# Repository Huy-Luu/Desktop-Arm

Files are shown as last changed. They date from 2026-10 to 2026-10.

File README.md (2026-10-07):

# 🦾 Desktop AI Robot Arm

An educational, 6-DOF (Degree of Freedom) desktop robotic manipulator integrated with the **Desktop Assistant** companion robot, serving as a hands-on learning laboratory for mastering **Robotic AI, Google MuJoCo Simulation, Reinforcement Learning, Embedded Firmware, KiCad PCB, and FreeCAD CAD**.

---

## 📌 Start Here

If you are returning to this project or starting a new session, open the dedicated beginner guide:
👉 **[📖 Beginner Guide & Master Roadmap](docs/BEGINNER_GUIDE_AND_ROADMAP.md)**

This guide explains:
1. **Why we train in simulation first** (Safety, Speed, and Instant Iteration).
2. **Key concepts demystified** (*Homography, Synthetic Test Harness, Domain Randomization, ONNX*).
3. **The 4-Phase Master Roadmap** from virtual simulation to physical desk manipulation.
4. **Current ticket status & next steps**.

---

## 🏛️ Project Directory Structure

```text
deskto-AI-arm/
├── README.md                      # Project root overview (this file)
├── MISSION.md                     # Why this project exists & definition of success
├── GLOSSARY.md                    # Ubiquitous robotics & AI domain dictionary
├── NOTES.md                       # Architectural decisions & hardware preferences
├── RESOURCES.md                   # High-trust documentation and community links
│
├── docs/
│   ├── BEGINNER_GUIDE_AND_ROADMAP.md # Comprehensive guide and master roadmap
│   ├── SYSTEM_DESIGN_DOCUMENT.md     # Authoritative Master System Design Document
│   ├── SPEC-0001-desktop-ai-arm.md   # Complete system architecture specification
│   ├── adr/                          # Architectural Decision Records (ADRs 0001–0005)
│   └── tickets/                      # Tracer-bullet tickets (TICKET-01 to TICKET-12)
│
├── software/
│   ├── models/
│   │   └── desktop_arm_6dof.xml      # Google DeepMind MuJoCo 6-DOF arm physics model
│   ├── arm_env_3d.py                 # Gymnasium continuous-control environment
│   ├── test_sim.py                   # Sanity test verifying 6-DOF physics simulation
│   ├── train_arm_3d_6dof.ipynb       # Google Colab GPU training notebook (PPO)
│   └── gemini_vision_planner.py      # Google Gemini 2.0 Flash spatial perception
│
├── hardware/                         # FreeCAD 3D models & KiCad base controller schematics
├── firmware/                         # ESP32-S3 FreeRTOS motor control & StallGuard4 homing
└── reference/                        # Quick-reference cheatsheets & fundamentals
```

---

## 🚦 Current Status & Next Step

- **TICKET-01 (Simulation Verification)**: ✅ **COMPLETED**. MuJoCo 6-DOF environment verified with [test_sim.py](file:///mnt/g/projects/deskto-AI-arm/software/test_sim.py).
- **TICKET-02 (Colab PPO Training & ONNX Export)**: ✅ **COMPLETED**. Vectorized notebook with Domain Randomization and ONNX actor export ready in [software/train_arm_3d_6dof.ipynb](file:///mnt/g/projects/deskto-AI-arm/software/train_arm_3d_6dof.ipynb). See [Lesson 0001](file:///mnt/g/projects/deskto-AI-arm/lessons/0001-colab-ppo-and-domain-randomization.html) and [test_ticket02.py](file:///mnt/g/projects/deskto-AI-arm/software/test_ticket02.py).
- **TICKET-03 (Local PC ONNX Inference & Workspace Geofence)**: 🎯 **CURRENT NEXT STEP**. Deploy `arm_policy.onnx` locally on CPU with 3D table safety boundaries.

To resume at any time in a new chat, simply tell the assistant:
> *"I'm ready to continue. Let's work on TICKET-03 (Local PC ONNX Inference and Workspace Geofencing)."*

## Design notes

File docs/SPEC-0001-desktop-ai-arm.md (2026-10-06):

# SPEC-0001: Desktop AI Robot Arm & Desktop Assistant Integration

- **Status**: Ready for Implementation (`ready-for-agent`)
- **Date**: 2026-10-04
- **Related ADRs**:
  - [ADR 0001: Hybrid Stepper-Servo Actuation & Wireless Docking](file:///mnt/g/projects/deskto-AI-arm/docs/adr/0001-hybrid-stepper-servo-and-wireless-docking.md)
  - [ADR 0002: Sensorless Homing, Base-Mounted Belt Drive, and WebSocket Architecture](file:///mnt/g/projects/deskto-AI-arm/docs/adr/0002-sensorless-homing-base-steppers-and-websockets.md)
  - [ADR 0003: 24V Bus, PLA Thermal Mitigation, and Rack-and-Pinion Gripper](file:///mnt/g/projects/deskto-AI-arm/docs/adr/0003-power-delivery-thermal-pla-and-rack-pinion-gripper.md)
  - [ADR 0004: Conversational Disambiguation, ONNX Runtime Inference, and Domain Randomization](file:///mnt/g/projects/deskto-AI-arm/docs/adr/0004-conversational-ambiguity-onnx-and-domain-randomization.md)
  - [ADR 0005: Hierarchical Grasping, Overhead Homography, and S-Curve Motion Execution](file:///mnt/g/projects/deskto-AI-arm/docs/adr/0005-hierarchical-grasping-homography-and-scurve-motion.md)
- **Authoritative Master Design**: [SYSTEM_DESIGN_DOCUMENT.md](file:///mnt/g/projects/deskto-AI-arm/docs/SYSTEM_DESIGN_DOCUMENT.md)

---

## Problem Statement

As a beginner to robotics, AI, and electronics, building a desktop manipulator from scratch is daunting due to the complex convergence of mechanical design, kinematics math, PCB layout, and modern neural network control. Furthermore, desktop robots typically lack emotional personality and intuitive natural language interfaces, while existing hobby arms suffer from servo jitter, gear backlash, loud whining, and dangerous lack of collision detection.

The user needs a modular, quiet, precise desktop 6-DOF robot arm that physically integrates with their sibling **Desktop Assistant** (providing expressive eyes and voice interaction), uses cloud compute (Google Colab / MuJoCo) for accelerated AI training, and executes safe, intelligent object manipulation on a desk.

---

## Solution

A desktop-sized 6-DOF hybrid manipulator featuring:
1. **Physical & Electrical Dock**: An arm base cradle with ENIG gold pads mating with Desktop Assistant's `KZM05P03UFT2-B` pogo pins, delivering 5V 3A charging and automatic dock presence detection.
2. **Hybrid Stepper-Servo Drive**: NEMA 14/17 steppers with Trinamic TMC2209 silent drivers and GT2 belt reduction for the high-torque base and shoulder/elbow joints, combined with lightweight micro-servos for the wrist and rack-and-pinion gripper.
3. **Sensorless Homing & Safety**: StallGuard4 back-EMF detection for wire-free homing and automatic emergency cut-off upon collision, backed by software workspace geofencing.
4. **Cloud-Trained Sim-to-Real Policy**: A continuous-control PPO policy trained with domain randomization in Google DeepMind's MuJoCo physics engine on Google Colab, exported to ONNX for lightweight sub-5ms local PC execution.
5. **Conversational Multi-Modal Intelligence**: Overhead webcam scene parsing via Google Gemini 2.0 Flash with conversational disambiguation streamed through Desktop Assistant's microphone and speaker.

---

## User Stories

1. As a user, I want to dock my Desktop Assistant onto the robot arm's base cradle, so that its battery charges automatically via pogo pins.
2. As a user, I want the arm controller to instantly detect when Desktop Assistant is seated, so that it can trigger a greeting animation and report system readiness.
3. As a user, I want Desktop Assistant to continue working wirelessly on internal battery when unseated, so that I can hold it or place it anywhere on my desk while commanding the arm.
4. As a user, I want to speak natural voice commands (e.g., *"Pick up the marker"*) to Desktop Assistant, so that the robot performs object manipulation without requiring keyboard controls.
5. As a user, I want the robot to ask me for clarification through Desktop Assistant's speaker when multiple similar objects are on the table, so that it never grabs the wrong item by mistake.
6. As a user, I want Desktop Assistant's circular LCD to display expressive facial emotions (focused eyes while tracking, happy face on successful grasp, confused face on obstacle), so that the robotic system feels alive and engaging.
7. As a user, I want the arm's base and shoulder joints to operate silently using TMC2209 StealthChop2, so that the arm does not produce irritating high-pitch servo whine on my desk.
8. As a user, I want the arm to home itself automatically on boot without external limit switch wires, so that the mechanical links remain clean and aesthetically pleasing.
9. As a user, I want the arm to immediately stop and cut motor torque if it accidentally bumps into my hand or a desktop object, so that neither the 3D printed parts nor desk items are damaged.
10. As a user, I want to train the motion policy in Google DeepMind MuJoCo on Google Colab using free cloud GPUs, so that I can train complex neural control policies without requiring an expensive local GPU workstation.
11. As a user, I want the trained AI policy exported as an ONNX model, so that my local PC can run real-time inference with minimal CPU usage and zero PyTorch dependencies.
12. As a user, I want the AI policy trained with domain randomization in simulation, so that it transfers seamlessly to the physical 3D-printed arm despite minor belt compliance and friction differences.
13. As a user, I want the structural links printable in standard PLA with active thermal cooling, so that I can fabricate the arm on any basic 3D printer without warping.
14. As a user, I want a symmetrical parallel-jaw rack-and-pinion gripper, so that small cylindrical and rectangular desk items are grasped securely along the tool centerline.
15. As a developer, I want all messaging between PC, Desktop Assistant, and Arm Base to use structured JSON over WebSockets, so that telemetry and commands can be inspected easily in standard tools.

---

## Implementation Decisions

### 1. Electrical & Power Subsystem (Base Controller PCB)
- **Power Input**: 24V 5A DC barrel jack (2.1x5.5mm) with `SMBJ28A` TVS diode and P-channel MOSFET reverse polarity protection.
- **Buck Converter**: `TPS54302` (handles up to 28V input) generating 5.0V @ 3A for Desktop Assistant charging and servo bus, protected by a 2A PPTC resettable fuse.
- **LDO Regulator**: 3.3V low-dropout regulator for base ESP32-S3 MCU and logic.
- **Stepper Drivers**: 3x TMC2209 silent step/dir drivers configured over single-wire UART for software current control and StallGuard sensitivity tuning.
- **Dock Connector**: 5-pad ENIG gold interface matching Desktop Assistant `KZM05P03UFT2-B` pogo pins (`VBUS_5V`, `UART_TX`, `UART_RX`, `DOCK_DETECT_N`, `GND`).

### 2. Mechanical Subsystem (FreeCAD & PLA Fabrication)
- **Base Enclosure**: Encloses the base controller PCB, 24V input jack, 4010 cooling fan, and houses the Base Yaw NEMA 17 motor.
- **Top Deck**: Features a recessed cradle with dual N52 alignment magnets and gold pogo contact pads to hold Desktop Assistant.
- **Belt Drive**: 2GT synchronous timing belts (6mm width) transferring torque from base-mounted steppers to the shoulder and elbow pivot bearings.
- **End-Effector**: Dual rack-and-pinion parallel gripper driven by a single metal-gear micro-servo (MG90S) with silicone contact pads.

### 3. Firmware Subsystem (ESP32-S3 Arm Controller)
- **Framework**: ESP-IDF with FreeRTOS.
- **Stepper Engine**: Hardware timer generating smooth acceleration S-curves (Jerk-limited motion).
- **Homing State Machine**: Boots $\to$ lowers current to 200mA $\to$ moves towards hard stop $\to$ detects `DIAG` pin trigger $\to$ sets coordinate to zero $\to$ backs off 2mm $\to$ restores run current (600mA).
- **Network Interface**: WebSocket client connecting to PC WebSocket server; binary/JSON packet handler.

### 4. Software & AI Subsystem (Host PC & Google Colab)
- **Simulation**: Headless MuJoCo 3.x environment (`software/arm_env_3d.py`) modeling 6 articulated joints, table plane, and 3D reaching target.
- **Cloud Training**: Google Colab notebook (`software/train_arm_3d_6dof.ipynb`) running Stable-Baselines3 PPO with vectorized parallel environments and domain randomization.
- **Model Deployment**: Policy actor exported to `software/models/arm_policy.onnx`, evaluated locally on PC using `onnxruntime`.
- **Vision Pipeline**: Overhead webcam captures desk frame; Google Gemini 2.0 Flash (`software/gemini_vision_planner.py`) outputs target coordinates $[X, Y, Z]$ and handles conversational disambiguation.

---

## Testing Decisions

### Seams & Boundaries
1. **Simulation Seam (`DesktopArm3DEnv`)**: Verify the MuJoCo simulation environment independently via `software/test_sim.py` (reset, step, reward calculation, observation space bounds).
2. **ONNX Inference Seam**: Unit test verifying `onnxruntime` produces valid joint delta actions matching the PyTorch policy output within a numerical tolerance ($\epsilon < 10^{-4}$).
3. **Kinematics Math Seam**: Forward and Inverse Kinematics unit tests comparing analytical matrix calculations against MuJoCo physics forward kinematics.
4. **WebSocket Protocol Seam**: Mock WebSocket server testing message parsing, dock presence events, and emergency stop trigger responses.
5. **Firmware Motor Seam**: Hardware-in-the-loop test commanding 1,000 microsteps and verifying zero step loss.

---

## Out of Scope

- High-voltage industrial servo drives (48V+).
- Heavy metal CNC milling of arm links (all parts optimized for FDM 3D printing).
- SLAM or mobile navigation (the arm base is a desktop stationary unit).
- Training vision models from scratch (leveraging Google Gemini 2.0 Flash foundation model).

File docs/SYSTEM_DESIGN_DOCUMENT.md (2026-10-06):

# SYSTEM-DESIGN-0001: Desktop AI Robot Arm & Desktop Assistant Ecosystem

- **Document Version**: 1.0.0
- **Status**: Authoritative Master Design Specification (`approved-for-execution`)
- **Date**: 2026-10-06
- **System Deciders**: User & Antigravity Engineering Pair
- **Associated ADRs**:
  - [ADR 0001: Hybrid Stepper-Servo Actuation & Wireless Docking](file:///mnt/g/projects/deskto-AI-arm/docs/adr/0001-hybrid-stepper-servo-and-wireless-docking.md)
  - [ADR 0002: Sensorless Homing, Base-Mounted Belt Drive, and WebSocket Architecture](file:///mnt/g/projects/deskto-AI-arm/docs/adr/0002-sensorless-homing-base-steppers-and-websockets.md)
  - [ADR 0003: 24V Bus, PLA Thermal Mitigation, and Rack-and-Pinion Gripper](file:///mnt/g/projects/deskto-AI-arm/docs/adr/0003-power-delivery-thermal-pla-and-rack-pinion-gripper.md)
  - [ADR 0004: Conversational Disambiguation, ONNX Runtime Inference, and Domain Randomization](file:///mnt/g/projects/deskto-AI-arm/docs/adr/0004-conversational-ambiguity-onnx-and-domain-randomization.md)
  - [ADR 0005: Hierarchical Grasping, Overhead Homography, and S-Curve Motion Execution](file:///mnt/g/projects/deskto-AI-arm/docs/adr/0005-hierarchical-grasping-homography-and-scurve-motion.md)
- **Domain Glossary**: [GLOSSARY.md](file:///mnt/g/projects/deskto-AI-arm/GLOSSARY.md)
- **Project Mission**: [MISSION.md](file:///mnt/g/projects/deskto-AI-arm/MISSION.md)

---

## 1. Executive Summary & System Vision

The **Desktop AI Robot Arm** is a modular, desktop-scale 6-DOF robotic manipulation system integrated with a companion **Desktop Assistant**. It serves as an accessible, high-performance hands-on laboratory for mastering modern robotic artificial intelligence, Google cloud-accelerated reinforcement learning, embedded motion firmware, PCB design, and mechanical engineering.

```
       ┌────────────────────────────────────────────────────────┐
       │             Google Colab Cloud Training                │
       │  - Headless MuJoCo 3.x Physics (16 Parallel Envs)     │
       │  - Stable-Baselines3 PPO with Domain Randomization     │
       │  - Exports: software/models/arm_policy.onnx           │
       └───────────────────────────┬────────────────────────────┘
                                   │ Model Download (.onnx)
                                   ▼
┌───────────────────────────┐             ┌─────────────────────────────┐
│    Overhead Camera Rig    │             │   Desktop Assistant Head    │
│  - Fixed table view       │             │  - Circular LCD face/eyes   │
│  - 4-point ArUco homography│             │  - Voice mic & speaker      │
└─────────────┬─────────────┘             │  - Untethered Wi-Fi battery │
              │ Video Frames              └──────────────┬──────────────┘
              ▼                                          │ Audio / UI Events
┌────────────────────────────────────────────────────────┴──────────────┐
│                    Host PC Orchestration Engine                       │
│  - Perception: Google Gemini 2.0 Flash (Spatial Object Reasoning)     │
│  - Disambiguation: Multi-turn conversational clarification           │
│  - Motion Brain: Local ONNX Runtime (<5ms CPU inference)              │
│  - Safety: 3D Cartesian Workspace Geofence Layer                      │
│  - Communication Broker: Full-Duplex JSON-over-WebSocket Server       │
└──────────────────────────────────┬────────────────────────────────────┘
                                   │ Target Waypoints & Commands (JSON)
                                   ▼
┌───────────────────────────────────────────────────────────────────────┐
│               Arm Base Controller & Physical Robot                    │
│  - MCU: ESP32-S3 (Dual-core 240MHz, FreeRTOS, S-Curve Step Generator) │
│  - Power: 24V 5A DC bus + TPS54302 Buck (5V 3A) + 3.3V LDO            │
│  - Steppers: 3x TMC2209 silent drivers (Base, Shoulder, Elbow)        │
│  - Servos: 3x Metal-gear micro-servos (Forearm, Wrist, Gripper)       │
│  - Dock: 5-pad ENIG gold pogo cradle (5V charging + dock presence)    │
│  - Safety: StallGuard4 sensorless homing + obstacle torque cut-off   │
└───────────────────────────────────────────────────────────────────────┘
```

### Core Design Pillars
1. **Simulation-First Development**: Full physics modeling in Google DeepMind MuJoCo before physical fabrication, guaranteeing zero hardware damage, 20-minute cloud GPU training runs, and rapid kinematic tuning.
2. **Hierarchical Control Pipeline**: Decoupling 3D spatial reaching (learned by cloud PPO) from contact-rich grasping (executed by deterministic descent-pinch-lift motion primitives) to achieve rock-solid physical tabletop reliability.
3. **Silent Desktop Presence**: Combining Trinamic TMC2209 StealthChop2 silent stepper drivers for high-torque base axes with lightweight metal-gear micro-servos for the wrist, eliminating irritating servo buzz and whine.
4. **Seamless Companion Symbiosis**: The Desktop Assistant mechanically and electrically seats into an ENIG gold pogo dock on the arm's base, receiving 5V 3A charging and providing expressive eyes, speech, and conversational disambiguation.

---

## 2. End-to-End System Architecture & Data Flow

```mermaid
sequenceDiagram
    autonumber
    actor User as User
    participant Head as Desktop Assistant (Head)
    participant PC as Host PC Orchestrator
    participant Cloud as Gemini 2.0 Flash API
    participant ONNX as ONNX Inference Engine
    participant Arm as ESP32-S3 Base Controller
    participant Cam as Overhead Camera

    Note over Arm,Head: System Boot & Calibration
    Arm->>Arm: Execute StallGuard4 Sensorless Homing (200mA)
    Arm-->>PC: WebSocket: ARM_STATUS (homed=true, docked=true)
    Head-->>PC: WebSocket: ASSISTANT_STATUS (battery=100%, state=idle)

    Note over User,Arm: Task Execution Flow
    User->>Head: "Pick up the blue marker"
    Head->>PC: Stream user audio transcript
    PC->>Cam: Capture desk frame (1920x1080)
    PC->>Cloud: Send image + instruction prompt
    
    alt Ambiguity Detected (Multiple Blue Objects)
        Cloud-->>PC: JSON {action: "disambiguate", prompt: "Which blue marker?"}
        PC->>Head: Play voice prompt & display questioning eyes
        User->>Head: "The one near the notebook"
        Head->>PC: Forward clarification
        PC->>Cloud: Re-prompt with context
    end

    Cloud-->>PC: JSON {target_detected: true, u_norm: 0.52, v_norm: 0.64, grasp_yaw: 0.0}
    PC->>PC: Homography Transform: (u, v) -> Table (X, Y) in meters
    PC->>PC: Formulate Pre-Grasp Waypoint: P_pre = (X, Y, Z_table + 0.05m)
    
    loop 40Hz Policy Rollout (or Direct IK Waypoint)
        PC->>ONNX: Evaluate policy(obs) -> joint_deltas
        PC->>PC: Apply 3D Workspace Geofence Bounds
    end

    PC->>Arm: Send ARM_MOVE_WAYPOINT (joint_angles, speed_profile)
    Arm->>Arm: ESP32 Jerk-Limited S-Curve Step Interpolation
    Arm-->>PC: WebSocket: ARM_STATUS (waypoint_reached=true)

    Note over PC,Arm: Deterministic Grasp Primitive
    PC->>Arm: Command vertical descent (-50mm along Z)
    Arm->>Arm: Step motors down to object height
    PC->>Arm: Command GRIPPER_COMMAND (action=close, width=15mm)
    Arm->>Arm: Actuate MG90S gripper micro-servo
    PC->>Arm: Command vertical lift (+80mm along Z)
    Arm->>Arm: Step motors upward with payload
    Head->>Head: Display happy eyes & chime confirmation
```

---

## 3. Kinematic & Mechanical Subsystem Specification

### 3.1 Kinematic Chain & Joint Parameters

The arm is configured as a 6-DOF articulated serial manipulator with an open-chain kinematic structure:

| Joint | Anatomical Name | Motion Type | Axis of Rotation | Angular Range | Actuator Type | Transmission / Reduction | Max Velocity |
|---|---|---|---|---|---|---|---|
| **Joint 1** | Base Yaw | Revolute | $Z$-axis (vertical) | $[-180^\circ, +180^\circ]$ | NEMA 17 Stepper (17HS4401) | 3:1 GT2 Belt ($16\text{T} \to 48\text{T}$) | $180^\circ/\text{s}$ |
| **Joint 2** | Shoulder Pitch | Revolute | $Y$-axis (horizontal) | $[-90^\circ, +90^\circ]$ | NEMA 17 Stepper (17HS4401) | 4:1 GT2 Belt ($16\text{T} \to 64\text{T}$) | $120^\circ/\text{s}$ |
| **Joint 3** | Elbow Pitch | Revolute | $Y$-axis (horizontal) | $[-120^\circ, +120^\circ]$ | NEMA 14 Stepper (14HS13-0804S) | 3:1 GT2 Belt ($16\text{T} \to 48\text{T}$) | $150^\circ/\text{s}$ |
| **Joint 4** | Forearm Roll | Revolute | $Z'$-axis (along link) | $[-180^\circ, +180^\circ]$ | MG90S Metal Micro-Servo | Direct horn coupling | $300^\circ/\text{s}$ |
| **Joint 5** | Wrist Pitch | Revolute | $Y'$-axis (lateral) | $[-90^\circ, +90^\circ]$ | MG90S Metal Micro-Servo | Direct horn coupling | $300^\circ/\text{s}$ |
| **Joint 6** | Tool Roll | Revolute | $Z''$-axis (end-effector) | $[-180^\circ, +180^\circ]$ | MG90S Metal Micro-Servo | Direct spur pinion drive | $300^\circ/\text{s}$ |

### 3.2 Link Dimensions & Workspace Reach Envelope

- **Base Offset ($d_1$)**: $60\text{ mm}$ (table surface to shoulder pivot center).
- **Upper Arm Link ($a_2$)**: $140\text{ mm}$ (shoulder pivot to elbow pivot).
- **Forearm Link ($a_3$)**: $120\text{ mm}$ (elbow pivot to wrist pitch pivot).
- **Wrist / Tool Flange ($d_5$)**: $65\text{ mm}$ (wrist pivot to gripper fingertip contact center).
- **Kinematic Workspace Envelope**:
  - Horizontal Reach: $R_{min} = 120\text{ mm}$, $R_{max} = 280\text{ mm}$ (nominal tabletop radius).
  - Vertical Reach: $Z_{min} = 150\text{ mm}$ (tabletop plane), $Z_{max} = 380\text{ mm}$.
  - Rated Grasp Payload: $150\text{ g}$ nominal ($250\text{ g}$ absolute limit).

### 3.3 Base-Mounted Belt Transmission Layout

To prevent cantilever inertia from destabilizing the 3D-printed arm, the heavy stepper motors for Joints 1, 2, and 3 are mounted in the base structure:
- **Base Enclosure**: Contains the Joint 1 NEMA 17 motor driving the rotating turret via a large internal bearing (6708ZZ, $40\times 50\times 6\text{ mm}$).
- **Turret Deck**: Houses the Joint 2 NEMA 17 and Joint 3 NEMA 14 motors side-by-side.
- **Shoulder & Elbow Drive**: Dual concentric 2GT belts route upward along the Link 2 chassis. Joint 3 torque is transferred across the shoulder pivot via an idler bearing stack to isolate elbow rotation from shoulder movement.

### 3.4 Parallel-Jaw Rack-and-Pinion Gripper

```
           [  MG90S Micro-Servo  ]
                     │
              [ Spur Pinion (12T) ]
                ┌────┴────┐
                ▼         ▼
  [ Left Rack ◄ ]         [ ► Right Rack ]
         │                       │
   [ Silicone Pad ]        [ Silicone Pad ]
```
- A single MG90S metal-gear micro-servo drives a central 12-tooth spur pinion.
- The pinion simultaneously engages two opposing gear racks with linear guide rails.
- Linear jaw travel: $0\text{ mm}$ (fully closed) to $45\text{ mm}$ (fully open).
- Gripper finger tips feature $1.5\text{ mm}$ molded or adhesive silicone rubber pads with a friction coefficient $\mu \ge 0.8$, allowing firm grasping of smooth markers, plastic cubes, and metal tools.

### 3.5 Mechanical Fabrication & Thermal Mitigation
- **Filament**: Standard PLA / PLA+ with $40\%$ infill (gyroid pattern) and 4 perimeters for structural rigidity.
- **Thermal Strategy**: PLA has a low glass transition temperature ($T_g \approx 58^\circ\text{C}$). Stepper motors can easily reach $60^\circ\text{C}-70^\circ\text{C}$ under continuous holding current.
  - Base CAD incorporates an intake vent with a quiet $4010$ $24\text{V}$ brushless blower fan directing cool airflow across motor bodies and driver heatsinks.
  - Firmware enforces an automatic **Standby Hold Current** reducing coil current to $30\%$ whenever any joint remains stationary for $>200\text{ ms}$.

---

## 4. Electrical Subsystem Specification (Base Controller PCB)

### 4.1 Power Architecture Tree

```
[ 24V 5A DC Jack ] (2.1x5.5mm)
        │
        ├──► [ SMBJ28A TVS ] ──► [ P-FET Reverse Polarity ] ──► [ 24V VMOT Motor Rail ]
        │                                                              │
        │                                                ┌─────────────┴─────────────┐
        │                                                ▼                           ▼
        │                                          [ 3x TMC2209 ]               [ 4010 Fan ]
        │                                         (100uF 35V Caps)
        │
        └──► [ TPS54302 Synchronous Buck Converter ] (Step-Down 24V -> 5.0V @ 3A)
                     │
                     ├──► [ 2A PPTC Resettable Fuse ] ──► [ Pogo Pin Dock: VBUS_5V (Assistant) ]
                     ├──► [ Servo Rail 5V ] ─────────────► [ 3x MG90S Micro-Servos ]
                     │
                     └──► [ ME6211 / AMS1117-3.3 LDO ] ──► [ 3.3V Logic Bus ]
                                                                   │
                                                                   ├──► [ ESP32-S3 MCU ]
                                                                   ├──► [ TMC2209 VIO ]
                                                                   └──► [ Status LEDs / Pull-ups ]
```

### 4.2 Power Delivery Specifications
- **Input Power**: $24\text{V} \pm 5\%$ DC, $5\text{A}$ ($120\text{W}$ rated), barrel jack $2.1\times 5.5\text{ mm}$, center-positive.
- **Overvoltage & Surge Clamping**: `SMBJ28A` unidirectional TVS diode clamping transient spikes below $45\text{V}$.
- **Reverse Polarity Protection**: P-Channel MOSFET (`AO3401A` or `AOD403`) with gate pulled to ground via $100\text{k}\Omega$ resistor and zener clamped at $12\text{V}$.
- **Buck Regulator (5V 3A)**: `TPS54302` switching at $500\text{kHz}$ with a $6.8\mu\text{H}$ shielded power inductor and $2\times 22\mu\text{F}$ ceramic output capacitors, delivering $<30\text{mV}$ peak-to-peak ripple.
- **Logic LDO (3.3V)**: `ME6211` low-noise LDO ($500\text{mA}$ peak) supplying the ESP32-S3 and digital logic.

### 4.3 Trinamic TMC2209 Stepper Driver Configuration
- **Drive Mode**: StealthChop2 (silent voltage PWM) for velocity $<100\text{ RPM}$; SpreadCycle automatically engaged if high dynamic acceleration is demanded.
- **Single-Wire UART Bus**: All 3 TMC2209 drivers share a single UART bus from ESP32-S3 (`GPIO17` TX, `GPIO18` RX with a $1\text{k}\Omega$ isolating resistor between TX and RX):
  - Driver 0 (Base Yaw): `MS1=GND`, `MS2=GND` (UART Address `0x00`).
  - Driver 1 (Shoulder Pitch): `MS1=VCC_IO`, `MS2=GND` (UART Address `0x01`).
  - Driver 2 (Elbow Pitch): `MS1=GND`, `MS2=VCC_IO` (UART Address `0x02`).
- **Sensorless Homing (`DIAG` Pin)**: StallGuard4 back-EMF output from each driver is wired to a dedicated hardware interrupt pin on the ESP32-S3.

### 4.4 Desktop Assistant Pogo Pin Interface

The top deck of the base enclosure features a 5-pad ENIG gold circular pad array matching Desktop Assistant's `KZM05P03UFT2-B` spring-loaded connector:

| Pad # | Signal Name | Electrical Characteristics | Subsystem Purpose |
|---|---|---|---|
| **Pad 1** | `VBUS_5V` | $+5.0\text{V} \pm 2\%$, max $2.5\text{A}$ | Desktop Assistant internal battery charging |
| **Pad 2** | `UART_TX` | $3.3\text{V}$ LVCMOS, $115200\text{ baud}$ | Base to Assistant hardware telemetry stream |
| **Pad 3** | `UART_RX` | $3.3\text{V}$ LVCMOS, $115200\text{ baud}$ | Assistant to Base motion command stream |
| **Pad 4** | `DOCK_DETECT_N`| Active-Low with $10\text{k}\Omega$ pull-up to $3.3\text{V}$ | Hardware dock seating detection |
| **Pad 5** | `GND` | Common Ground Return ($0\text{V}$) | System reference return |

### 4.5 Complete ESP32-S3 Pin Allocation Table

| GPIO Pin | Function / Peripheral | Direction | Connected Subsystem |
|---|---|---|---|
| `GPIO1` | `STEP_J1` | Output | Joint 1 (Base Yaw) TMC2209 Step |
| `GPIO2` | `DIR_J1` | Output | Joint 1 (Base Yaw) TMC2209 Dir |
| `GPIO3` | `STEP_J2` | Output | Joint 2 (Shoulder) TMC2209 Step |
| `GPIO4` | `DIR_J2` | Output | Joint 2 (Shoulder) TMC2209 Dir |
| `GPIO5` | `STEP_J3` | Output | Joint 3 (Elbow) TMC2209 Step |
| `GPIO6` | `DIR_J3` | Output | Joint 3 (Elbow) TMC2209 Dir |
| `GPIO7` | `EN_ALL_STEP` | Output (Active-Low) | Global Stepper Driver Enable |
| `GPIO8` | `DIAG_J1` | Input (IRQ) | Joint 1 StallGuard4 Collision/Endstop |
| `GPIO9` | `DIAG_J2` | Input (IRQ) | Joint 2 StallGuard4 Collision/Endstop |
| `GPIO10` | `DIAG_J3` | Input (IRQ) | Joint 3 StallGuard4 Collision/Endstop |
| `GPIO11` | `PWM_SERVO_J4` | Output (LEDC) | Joint 4 Forearm Roll Micro-Servo |
| `GPIO12` | `PWM_SERVO_J5` | Output (LEDC) | Joint 5 Wrist Pitch Micro-Servo |
| `GPIO13` | `PWM_SERVO_J6` | Output (LEDC) | Joint 6 Gripper Micro-Servo |
| `GPIO14` | `FAN_PWM` | Output (LEDC) | 4010 Cooling Fan Low-Side N-FET Gate |
| `GPIO15` | `DOCK_DETECT_N`| Input (IRQ / Pull-Up) | Pogo Dock Seating Detection |
| `GPIO16` | `LED_STATUS` | Output | RGB WS2812 Status LED Data |
| `GPIO17` | `TMC_UART_TX` | Output (UART1) | TMC2209 Configuration Bus TX |
| `GPIO18` | `TMC_UART_RX` | Input (UART1) | TMC2209 Configuration Bus RX |
| `GPIO19` | `DOCK_UART_TX`| Output (UART2) | Pogo Pin Dock Serial TX |
| `GPIO20` | `DOCK_UART_RX`| Input (UART2) | Pogo Pin Dock Serial RX |

---

## 5. Firmware Architecture (ESP32-S3 / ESP-IDF)

### 5.1 FreeRTOS Task Architecture

```
                  ┌──────────────────────────────────────────────┐
                  │                 ESP32-S3                     │
                  │                                              │
  Core 0 (Networking & Telemetry)       Core 1 (Real-Time Motion & Safety)
  ┌─────────────────────────────┐       ┌─────────────────────────────┐
  │ Task_Comm_WS                │       │ Task_Motion_Planner         │
  │ Priority: 5                 │       │ Priority: 18 (Real-time)    │
  │ - WebSocket Client (Wi-Fi)  │◄──Queue── - 7-Phase S-Curve Planner │
  │ - JSON Parser / Serializer  │       │ - Hardware Timer Interrupt  │
  │ - Assistant Pogo UART Sync  │       │ - Step pulse generation     │
  └─────────────────────────────┘       └──────────────┬──────────────┘
                 │                                     │
                 ▼                                     ▼
  ┌─────────────────────────────┐       ┌─────────────────────────────┐
  │ Task_Telemetry              │       │ Task_Safety_Supervisor      │
  │ Priority: 3                 │       │ Priority: 24 (Highest)      │
  │ - 20Hz Telemetry Broadcast  │       │ - StallGuard IRQ Handler    │
  │ - Thermal & Current Monitor │       │ - Dock Sense IRQ Handler    │
  └─────────────────────────────┘       │ - Instant E-Stop Cut-off    │
                                        └─────────────────────────────┘
```

### 5.2 Sensorless Homing State Machine (StallGuard4)

```mermaid
stateDiagram-v2
    [*] --> BOOT_INIT
    BOOT_INIT --> CONFIGURE_TMC: Read UART & Check Driver Comm
    CONFIGURE_TMC --> HOME_JOINT_1: Reduce Current to 200mA RMS
    
    HOME_JOINT_1 --> MOVE_TOWARD_STOP_1: Step slowly toward hardstop (30 RPM)
    MOVE_TOWARD_STOP_1 --> DETECT_STALL_1: StallGuard DIAG pin triggers
    DETECT_STALL_1 --> BACKOFF_1: Zero Axis Coordinate & Back off 2mm
    BACKOFF_1 --> HOME_JOINT_2: Repeat for Shoulder Joint
    
    HOME_JOINT_2 --> MOVE_TOWARD_STOP_2
    MOVE_TOWARD_STOP_2 --> DETECT_STALL_2
    DETECT_STALL_2 --> BACKOFF_2
    BACKOFF_2 --> HOME_JOINT_3: Repeat for Elbow Joint
    
    HOME_JOINT_3 --> MOVE_TOWARD_STOP_3
    MOVE_TOWARD_STOP_3 --> DETECT_STALL_3
    DETECT_STALL_3 --> BACKOFF_3
    BACKOFF_3 --> RESTORE_RUN_CURRENT: Restore 600mA Run Current
    
    RESTORE_RUN_CURRENT --> MOVE_TO_HOME_POSE: Move to Natural Resting Pose
    MOVE_TO_HOME_POSE --> READY_IDLE: System Operational
```

### 5.3 Jerk-Limited S-Curve Motion Profile Algorithm

To protect 3D-printed teeth and avoid motor resonance, motion commands are executed using a 7-phase S-curve profile where the jerk $j(t) = \frac{da}{dt}$ is bounded:

$$\begin{aligned}
j(t) &\le J_{max} \quad (1500^\circ/\text{s}^3) \\
a(t) &\le A_{max} \quad (300^\circ/\text{s}^2) \\
v(t) &\le V_{max} \quad (120^\circ/\text{s})
\end{aligned}$$

The profile divides motion into 7 discrete intervals:
1. **Linear Acceleration Ramp-up**: Jerk $= +J_{max}$, acceleration increases linearly to $A_{max}$.
2. **Constant Acceleration**: Jerk $= 0$, velocity increases linearly at $A_{max}$.
3. **Linear Acceleration Ramp-down**: Jerk $= -J_{max}$, acceleration decreases to $0$, velocity reaches $V_{max}$.
4. **Cruise Phase**: Jerk $= 0$, acceleration $= 0$, velocity $= V_{max}$.
5. **Deceleration Ramp-up**: Jerk $= -J_{max}$, deceleration increases to $-A_{max}$.
6. **Constant Deceleration**: Jerk $= 0$, velocity decreases linearly at $-A_{max}$.
7. **Deceleration Ramp-down**: Jerk $= +J_{max}$, deceleration decreases to $0$, reaching target waypoint at $V = 0$.

### 5.4 Dock Safety Interlock Behavior
- When `DOCK_DETECT_N` goes HIGH (indicating the Desktop Assistant was lifted off the cradle during motion):
  - Hardware interrupt fires within $<1\text{ ms}$.
  - `Task_Safety_Supervisor` immediately commands an emergency S-curve deceleration to a stationary hold.
  - WebSocket telemetry packet `{"event": "DOCK_UNDOCKED", "arm_state": "PAUSED"}` is emitted to PC.
  - The Desktop Assistant transitions to untethered Wi-Fi mode; user can inspect the scene and verbally confirm *"Continue"* or *"Cancel"*.

---

## 6. AI Perception & Reinforcement Learning Pipeline

### 6.1 Vision & Table Homography Perception

```
[ Overhead USB Webcam ] (1080p, looking straight down at desk)
         │
         ├── Step 1: ArUco / 4-Corner Calibration Matrix H (3x3)
         │           [X_real, Y_real, 1]^T = H * [u_norm, v_norm, 1]^T
         │
         └── Step 2: Google Gemini 2.0 Flash Spatial Prompting
```

#### Gemini 2.0 Flash Spatial Vision Schema
The host PC passes camera frames to Gemini 2.0 Flash along with the user's verbal instruction:
```json
{
  "system_instruction": "You are the spatial perception planner for a 6-DOF desktop robot manipulator. Identify the target item matching the user's intent. Output normalized coordinates (0.0 to 1.0) and detect any ambiguities.",
  "expected_output_schema": {
    "action": "execute_grasp | disambiguate | target_not_found",
    "clarification_question": "string | null",
    "target_detected": true,
    "object_class": "blue marker",
    "normalized_centroid": {"u": 0.542, "v": 0.618},
    "bounding_box": [0.51, 0.58, 0.57, 0.65],
    "approach_yaw_degrees": 15.0,
    "confidence": 0.94
  }
}
```

#### Conversational Disambiguation Flow
If multiple similar items reside on the desk (e.g., two blue pens), Gemini outputs `"action": "disambiguate"`. The PC relays this to Desktop Assistant, which prompts the user verbally (*"I see two blue pens. Do you want the one near the notebook or the one in the center?"*) while displaying an inquisitive expression on its circular LCD.

### 6.2 MuJoCo Gymnasium Continuous Control Environment

The simulation environment is defined in [software/arm_env_3d.py](file:///mnt/g/projects/deskto-AI-arm/software/arm_env_3d.py) with the physical robot model in [software/models/desktop_arm_6dof.xml](file:///mnt/g/projects/deskto-AI-arm/software/models/desktop_arm_6dof.xml):

- **Action Space**: $\text{Box}(-1.0, 1.0, \text{shape}=(6,), \text{float32})$
  Continuous joint position deltas: $\Delta q_i = a_i \times \Delta \theta_{max}$, where $\Delta \theta_{max} = 0.05\text{ rad}$ ($2.86^\circ$).
- **Observation Space**: $\text{Box}(-\infty, +\infty, \text{shape}=(27,), \text{float32})$
  $$\mathcal{O} = [\cos(q_{0..5}), \sin(q_{0..5}), \dot{q}_{0..5}, p_{ee}, p_{target}, (p_{target} - p_{ee})]$$
  - $\cos(q), \sin(q)$: Continuous representation of 6 joint angles, avoiding $2\pi$ wrap-around singularities ($12\text{ dims}$).
  - $\dot{q}$: Joint angular velocities ($6\text{ dims}$).
  - $p_{ee}$: Current 3D Cartesian coordinates of end-effector tracking site ($3\text{ dims}$).
  - $p_{target}$: Target 3D coordinates $(X, Y, Z)$ in meters ($3\text{ dims}$).
  - $(p_{target} - p_{ee})$: 3D vector difference directly informing the actor of spatial distance and approach heading ($3\text{ dims}$).

- **Reward Function**:
  $$R_t = -\|p_{ee} - p_{target}\|_2 - 0.005 \sum_{i=1}^6 a_i^2 + R_{bonus}$$
  Where:
  $$R_{bonus} = \begin{cases} 
  +2.0 & \text{if } \|p_{ee} - p_{target}\| < 0.03\text{ m} \quad (\text{Success condition}) \\
  +0.5 & \text{if } \|p_{ee} - p_{target}\| < 0.06\text{ m} \quad (\text{Proximity shaping}) \\
  0.0 & \text{otherwise}
  \end{cases}$$

### 6.3 Domain Randomization (Sim-to-Real Bridge)

During PPO training on Google Colab, physical dynamics parameters are perturbed across episodes:
- **Joint Friction & Damping**: $D_{joint} \sim \mathcal{U}(0.8 \times D_0, 1.2 \times D_0)$ ($\pm 20\%$).
- **Link Masses & Center-of-Mass**: $M_{link} \sim \mathcal{U}(0.85 \times M_0, 1.15 \times M_0)$ ($\pm 15\%$).
- **Actuation Latency**: Injected queue delay $t_{delay} \sim \mathcal{U}(10\text{ ms}, 30\text{ ms})$ to model Wi-Fi and buffer delays.
- **Action Noise**: Gaussian perturbation $\epsilon \sim \mathcal{N}(0, 0.02\text{ rad})$ injected into motor step increments.

### 6.4 Model Export & Local Host PC Execution
1. Following convergence on Google Colab (>85% success rate), the policy actor network is exported to ONNX format:
   ```python
   torch.onnx.export(
       model.policy.mlp_extractor.policy_net,
       dummy_observation,
       "software/models/arm_policy.onnx",
       input_names=["observation"],
       output_names=["action"],
       dynamic_axes={"observation": {0: "batch"}, "action": {0: "batch"}}
   )
   ```
2. The host PC executes `software/models/arm_policy.onnx` via `onnxruntime` (<5ms CPU latency per forward pass).
3. **Workspace Geofence Layer**: The output trajectory is clamped within physical boundaries:
   $$\begin{aligned}
   0.12\text{ m} &\le \sqrt{X^2 + Y^2} \le 0.28\text{ m} \\
   0.165\text{ m} &\le Z \le 0.380\text{ m}
   \end{aligned}$$
   This mathematically prevents the robot from driving into the table surface or self-colliding with the base enclosure.

### 6.5 Hierarchical Grasp Execution Sequence

```mermaid
flowchart TD
    START([1. Vision Detection]) --> P1[2. Homography Transform: u,v to Table X,Y]
    P1 --> P2["3. Pre-Grasp Waypoint: P_pre = (X, Y, Z_table + 50mm, Yaw)"]
    P2 --> RL["4. Colab-Trained PPO Policy Guides Arm to P_pre"]
    RL --> CHECK{"Dist(ee, P_pre) < 15mm?"}
    CHECK -- No --> RL
    CHECK -- Yes --> D1["5. Descent Primitive: Linear Descent 50mm down Z"]
    D1 --> G1["6. Gripper Primitive: Micro-Servo Closes Jaws to Pinch"]
    G1 --> L1["7. Lift Primitive: Linear Lift 80mm up Z"]
    L1 --> SUCCESS([8. Grasp Complete: Ready for Placement])
```

---

## 7. Communication & Protocol Specification

All communication between the Host PC, Desktop Assistant, and Base Controller flows as structured JSON over full-duplex WebSockets.

### 7.1 Telemetry Broadcast (`ARM_STATUS`)
Emitted periodically at $20\text{ Hz}$ by ESP32-S3:
```json
{
  "type": "ARM_STATUS",
  "timestamp_ms": 1425890,
  "homed": true,
  "dock_seated": true,
  "state": "IDLE | EXECUTING | PAUSED | ESTOP",
  "joint_angles_deg": [12.4, 45.0, -32.1, 0.0, 15.0, 0.0],
  "end_effector_pos_m": [0.185, 0.042, 0.215],
  "gripper_width_mm": 45.0,
  "bus_voltage_v": 24.1,
  "current_ma": 420,
  "tmc_temperature_c": 38.5,
  "last_error": null
}
```

### 7.2 Waypoint Motion Command (`ARM_MOVE_WAYPOINT`)
Sent from Host PC to ESP32-S3:
```json
{
  "type": "ARM_MOVE_WAYPOINT",
  "command_id": "cmd_9482",
  "target_joint_angles_deg": [25.0, 35.0, -20.0, 0.0, 10.0, 0.0],
  "max_velocity_pct": 80,
  "acceleration_time_ms": 400,
  "blend_radius_mm": 10.0
}
```

### 7.3 Gripper Actuation Command (`GRIPPER_COMMAND`)
Sent from Host PC to ESP32-S3:
```json
{
  "type": "GRIPPER_COMMAND",
  "command_id": "grp_102",
  "action": "open | close | set_width",
  "target_width_mm": 20.0,
  "holding_torque_pct": 75
}
```

### 7.4 Safety & Collision Alert (`SAFETY_ALERT`)
Sent from ESP32-S3 to Host PC upon StallGuard trigger or geofence violation:
```json
{
  "type": "SAFETY_ALERT",
  "timestamp_ms": 1426110,
  "trigger": "STALLGUARD_OBSTACLE | GEOFENCE_LIMIT | EMERGENCY_STOP",
  "axis_affected": "JOINT_2_SHOULDER",
  "stall_load_value": 482,
  "action_taken": "TORQUE_CUT_DECELERATED",
  "recommended_user_action": "Inspect workspace for obstacles and confirm resume"
}
```

---

## 8. Sim-to-Real Bringup, Calibration & Testing Seams

### 8.1 Testing Seams & Verification Gates

```
┌────────────────────────────────────────────────────────────────────────┐
│                        Master Testing Seams                            │
├────────────────────────────────┬───────────────────────────────────────┤
│ Seam 1: MuJoCo Physics Sim     │ software/test_sim.py                  │
│                                │ Verifies 27-dim obs, bounds & reward  │
├────────────────────────────────┼───────────────────────────────────────┤
│ Seam 2: Synthetic Vision       │ software/test_synthetic_vision.py     │
│                                │ Verifies Gemini JSON & Homography     │
├────────────────────────────────┼───────────────────────────────────────┤
│ Seam 3: ONNX Inference & Fence │ software/test_onnx_geofence.py        │
│                                │ Verifies <5ms forward pass & clamping │
├────────────────────────────────┼───────────────────────────────────────┤
│ Seam 4: WebSocket Protocol     │ software/test_ws_protocol.py          │
│                                │ Verifies full-duplex JSON schema      │
├────────────────────────────────┼───────────────────────────────────────┤
│ Seam 5: Embedded Stepper HIL   │ firmware/test_stepper_hil.c           │
│                                │ Verifies step accuracy & StallGuard   │
└────────────────────────────────┴───────────────────────────────────────┘
```

### 8.2 Bringup Procedure (Step-by-Step)
1. **Kinematic Dimension Audit**: Measure physical 3D-printed link lengths from pivot to pivot and verify exact match with `desktop_arm_6dof.xml`.
2. **StallGuard Sensitivity Sweep**: Run automated tuning firmware script sweeping `SGTHRS` from $0$ to $255$ against mechanical hardstops to identify the sweet spot without false triggers.
3. **Overhead Camera Homography Calibration**: Place an ArUco 4-corner calibration board on the desk. Run calibration script to compute and save the $H_{3\times 3}$ matrix.
4. **Open-Loop Waypoint Dry Run**: Command 5 discrete waypoints without an object. Verify smooth S-curve acceleration and correct end-effector height.
5. **Full Closed-Loop Sim-to-Real Pick-and-Place**: Place a 30mm colored cube on the table. Execute voice-driven pick, lift, and return.

---

## 9. Failure Modes, Hazards & Safety Interlocks Matrix

| Failure Mode / Hazard | Root Cause | Detection Mechanism | Immediate Firmware / System Action | Recovery Procedure |
|---|---|---|---|---|
| **Collision with Obstacle / Hand** | Foreign object obstructing arm path | TMC2209 StallGuard back-EMF spike on `DIAG` pin | FreeRTOS IRQ commands immediate torque cut / deceleration within $<2\text{ ms}$; emits `SAFETY_ALERT` | Clear obstacle; send resume command via Desktop Assistant or PC |
| **Tabletop Strike** | Target coordinate generated below desk surface | Host PC 3D Workspace Geofencing layer | Setpoint clamped to $Z \ge 0.165\text{ m}$ before packet is transmitted to ESP32 | Automatic; robot reaches safe minimum clearance |
| **Desktop Assistant Undocked During Motion** | User picks up Desktop Assistant from base | Hardware `DOCK_DETECT_N` pin pulled HIGH | Arm immediately executes controlled S-curve deceleration to stationary hold | Desktop Assistant switches to untethered Wi-Fi; asks user to confirm resume |
| **Belt Tooth Skipping** | Loose belt tension or excessive acceleration | StallGuard load deviation or visual misplacement | Motor stops if load exceeds threshold; S-curve profiles cap jerk to $1500^\circ/\text{s}^3$ | Re-tighten GT2 idler tensioning screw and re-home axis |
| **PLA Motor Mount Softening** | Heat transfer from motor cans ($>55^\circ\text{C}$) | Temperature sensor / duration monitor | Standby hold current automatically drops to $30\%$ during pauses; 4010 fan runs continuously | Check fan airflow duct; ensure firmware hold current is active |
| **Wi-Fi Packet Drop / Host Disconnect** | Network congestion or PC software crash | WebSocket heartbeat timeout ($>500\text{ ms}$) | ESP32-S3 automatically decelerates active motion to safe hold | Reconnect WebSocket; state restored automatically |
| **Visual Target Ambiguity** | Multiple identical objects matching query | Gemini 2.0 Flash confidence score and candidate list | Robot pauses; Assistant speaks clarification query and shows questioning face | User provides verbal disambiguation (*"The left one"*) |

---

## 10. Master Phasing & Milestone Roadmap

### Phase 1: Simulation & Virtual Brain (MuJoCo, Colab, ONNX)
- **TICKET-01**: MuJoCo 6-DOF Environment & Physics Verification. ✅ **COMPLETED**.
- **TICKET-02**: Colab PPO Training with Domain Randomization & ONNX Export. 🎯 **NEXT UP**.
- **TICKET-03**: Local PC ONNX Inference Engine & Workspace Geofence. ⏳ Blocked by 02.

### Phase 2: Vision & Assistant Interaction (Gemini & WebSockets)
- **TICKET-04**: Gemini 2.0 Flash Vision Planner & Homography Mapping. 🎯 **READY**.
- **TICKET-05**: WebSocket Orchestrator Bridge (PC + Assistant + Base MCU). ⏳ Blocked by 03, 04.

### Phase 3: Hardware & Electronics (KiCad PCB & FreeCAD 3D CAD)
- **TICKET-06**: Base PCB Power Tree (24V $\to$ 5V Buck $\to$ 3.3V LDO) & Pogo Dock. ⏳ Ready.
- **TICKET-07**: Base PCB Stepper & Servo Stage (3x TMC2209 UART & Micro-Servos). ⏳ Ready.
- **TICKET-08**: Base PCB Layout, Copper Routing, & Thermal Pours. ⏳ Blocked by 06, 07.
- **TICKET-09**: FreeCAD Mechanical Design: Base Enclosure, Cradle & Stepper Mounts. ⏳ Ready.
- **TICKET-10**: FreeCAD Mechanical Design: Rack-and-Pinion Parallel Gripper. ⏳ Ready.

### Phase 4: Embedded Firmware & Sim-to-Real Bringup (ESP32 & Real Desk)
- **TICKET-11**: ESP32-S3 Firmware (FreeRTOS, S-Curves, StallGuard4 Homing). ⏳ Blocked by 08.
- **TICKET-12**: Full System Bringup, Sim-to-Real Transfer & Tabletop Grasping. ⏳ Blocked by all.

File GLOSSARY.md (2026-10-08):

# Domain Glossary

Ubiquitous language for the Desktop AI Robot Arm project and its integration with Desktop Assistant.

## Core Robotic & AI Concepts

### 6-DOF Manipulator
A robotic arm with 6 Degrees of Freedom (Degrees of Freedom): Base Yaw, Shoulder Pitch, Elbow Pitch, Forearm Roll, Wrist Pitch, and Tool Roll/Gripper. 6-DOF allows the end-effector to reach any arbitrary position $(X, Y, Z)$ and orientation (Roll, Pitch, Yaw) within its physical workspace envelope.

### End-Effector (EE)
The tool or gripper at the end of the robotic kinematic chain that interacts with the physical world (e.g. grasping objects).

### Forward Kinematics (FK)
Calculating the 3D position and orientation of the end-effector $(X, Y, Z)$ given a known set of joint angles $(\theta_1, \theta_2, \dots, \theta_6)$. FK is deterministic and calculated using trigonometry and transformation matrices.

### Inverse Kinematics (IK)
The reverse problem: calculating what joint angles $(\theta_1, \dots, \theta_6)$ are required to position the end-effector at a desired 3D point $(X, Y, Z)$. IK often has multiple mathematical solutions or singularities.

### Reinforcement Learning (RL)
A machine learning paradigm where an agent learns through trial-and-error interaction with an environment, maximizing a numerical reward signal.

### Proximal Policy Optimization (PPO)
An actor-critic, on-policy reinforcement learning algorithm known for training stability and strong performance in continuous robotic control tasks.

### Sim-to-Real (Sim2Real)
The process of transferring an AI policy trained in a physics simulator (MuJoCo) onto physical hardware. Bridging the "reality gap" requires accurate motor models, latency simulation, and domain randomization.

### MJCF (MuJoCo XML Format)
The XML file format used by Google DeepMind's MuJoCo physics engine to define bodies, joints, geoms, materials, actuators, and sensors.

### Homography Coordinate Mapping
A 3x3 geometric perspective transformation matrix that maps 2D camera pixel coordinates $(u, v)$ from an overhead webcam viewing a flat table directly into real-world physical coordinates $(X, Y)$ (in meters) in MuJoCo and on the physical desk. It mathematically compensates for camera angle, tilt, and lens perspective distortion.

### Synthetic Test Harness
A standalone testing environment and script that feeds mock or simulated data (such as prerecorded camera frames, synthetic desk images, or simulated sensor readings) into a software module to verify its logic, parsing, and boundary handling deterministically without requiring physical hardware or live external sensors.

---

## Hardware & Actuation Terms

### Hybrid Stepper-Servo System
An actuation architecture combining NEMA 14/17 stepper motors for high-torque base/shoulder joints with lightweight metal-gear micro-servos for the wrist and end-effector.

### TMC2209 Stepper Driver
An ultra-quiet stepper driver IC featuring Trinamic StealthChop2 (silent stepping), SpreadCycle (high dynamic torque), and StallGuard4.

### StallGuard4 / Sensorless Homing
A technology that measures motor back-EMF to detect when a motor hits a physical mechanical endstop, allowing the arm to home itself without needing physical optical or microswitch limit switches.

### GT2 Timing Belt Reduction
A synchronous toothed belt system (2mm tooth pitch) used between stepper motor shafts and joint pivots to multiply torque, eliminate gear backlash, and allow motors to be mounted close to the base center of mass.

### Pogo Pin Dock
The spring-loaded pin interface (`KZM05P03UFT2-B`) used to dock the Desktop Assistant head onto the Arm Base Controller. It delivers 5V DC power, ground, and UART serial communication.

### ESP-NOW
A fast, low-latency, connectionless Wi-Fi protocol developed by Espressif allowing direct peer-to-peer packet transmission between the Desktop Assistant and Arm Base without going through a Wi-Fi router.

### 24V Power Bus
The high-voltage DC distribution rail supplying motor current to TMC2209 stepper drivers, providing superior torque-speed curves and lower current draw compared to 12V rails.

### Parallel-Jaw Rack & Pinion
A gripper mechanism where a central rotating spur pinion simultaneously drives two opposing toothed gear racks in opposite directions, keeping fingers parallel and centered on the grasping axis.

### Standby Hold Current
A TMC2209 firmware feature that automatically reduces motor coil current (e.g. down to 30% of run current) whenever an axis is stationary, preventing PLA motor mounts from softening due to motor heat.

### Conversational Disambiguation
An interaction pattern where the vision-language model detects ambiguity in the user's voice command and prompts Desktop Assistant to ask clarifying questions before initiating motor movements.

### ONNX (Open Neural Network Exchange)
An open, standardized model format enabling trained neural networks (such as our PPO actor policy) to be exported from Google Colab (PyTorch) and executed on the host PC with `onnxruntime` at sub-5ms latency without heavy AI dependencies.

### Domain Randomization (DR)
A sim-to-real transfer technique in which physics parameters (friction, mass, sensor noise, actuator latency) are randomly perturbed across training episodes in MuJoCo, teaching the neural network policy to be invariant to real-world hardware discrepancies.

### Hierarchical Control
An architecture that partitions a complex manipulation task into two distinct layers: a neural network (RL) policy responsible for free-space 3D reaching to a pre-grasp pose, and a deterministic motion primitive responsible for vertical descent, pinch, and lifting.

### Pre-Grasp Waypoint
A spatial target pose positioned at a designated safety clearance (e.g., 50mm) directly above the target object's centroid, oriented with the correct tool yaw angle for grasping.

### Deterministic Grasp Primitive
A scripted, open-loop or sensor-guided sequence executed after reaching the pre-grasp waypoint that performs linear descent along the Z-axis, closes the parallel gripper to a calibrated pinch width, and lifts the payload vertically.

### Jerk-Limited S-Curve Profile
A 7-phase motion acceleration profile where acceleration ramps smoothly up and down rather than stepping instantaneously (infinite jerk), minimizing mechanical vibration, belt backlash, and motor resonance.

### Table Homography Matrix
A 3x3 projective transformation matrix $H$ calibrated against 4 known table reference points that maps 2D camera pixels $(u, v)$ from an overhead webcam directly into real-world $(X, Y)$ table coordinates in meters.

### Safety Pause on Undock
A firmware-level interlock where removing Desktop Assistant from its pogo charging cradle causes the arm to decelerate safely to a halt, while retaining untethered Wi-Fi voice and display interaction.

---

## Pet Companion & Expressive Motion Concepts

### Expressive Robotics
A robotic design paradigm (pioneered by Disney Research, Sony AIBO, and Anki Vector) where robot motion conveys intent, emotion, personality, and life, rather than merely optimizing for shortest-time or industrial straight-line efficiency.

### Inquisitive Head-Tilt (Canine Roll Bias)
An expressive kinematic primitive where the end-effector (the "dog head") tilts sideways along its roll axis ($\pm 12^\circ$ to $\pm 18^\circ$) while maintaining visual gaze on a target object, signaling curiosity, questioning, or heightened attention.

### Idling / Breathing Oscillation
Subtle, continuous low-frequency (0.2 Hz – 0.5 Hz) harmonic or Perlin-noise oscillations injected into joint setpoints during idle states, giving the mechanical arm the illusion of breathing and resting life, preventing it from appearing "powered off" or dead.

### Compliant Interaction (Soft Joint Yield)
Motor control behavior where joint stiffness is intentionally limited (via current limiting or impedance control) so that when a human touches, strokes, or pushes the robot's head/neck, it gently yields and responds to touch rather than rigidly fighting the user.

### Behavior Tree (BT)
A modular hierarchical execution model used in robotics and game AI that evaluates environmental conditions (from Gemini vision and audio) to transition cleanly between distinct pet states (e.g. `SLEEPING`, `ALERT_TRACKING`, `CURIOUS_SNIFFING`, `PLAYFUL_NUDGE`, `GRASP_FETCH`).

### Trajectory Generator (Motion Planner)
A mathematical algorithm—hosted either on the host PC (streaming at 50Hz) or in ESP32 firmware—that translates a static target point into a continuous time-series of positions, velocities, and accelerations adhering to velocity limits and S-curve jerk constraints.

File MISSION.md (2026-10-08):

# Mission: Desktop AI Robot Arm

## Why
Build an intelligent, desktop-sized 6-DOF robotic arm integrated with the Desktop Assistant project, using this hands-on journey to master robotic AI (MuJoCo, RL, Google Colab/Cloud), CAD (FreeCAD), embedded firmware (ESP32), and circuit design (KiCad) as a beginner.

## Success looks like
- A simulated 6-DOF robotic arm environment in MuJoCo running at high speed on Google Colab.
- An AI policy trained via Reinforcement Learning (PPO) that can reach specified 3D targets `[X, Y, Z]` with organic, natural dynamics.
- An expressive **Pet Canine Companion persona**: the arm acts like an inquisitive desktop pet (with the gripper as its "dog head"), featuring curious head-tilting ($\pm 15^\circ$ roll bias), breathing/idle micro-oscillations, affectionate nudges, and playful sniffing.
- An integrated vision & voice pipeline: user speaks to Desktop Assistant / PC, Gemini 2.0 Flash detects target coordinates and human gestures from an overhead camera, and the robot responds dynamically.
- A physical Base Controller PCB with a pogo pin dock matching Desktop Assistant's `KZM05P03UFT2-B` interface, supplying power and UART communication.
- Solid understanding of robotic fundamentals: forward/inverse kinematics, trajectory generation (S-curves), sim-to-real transfer, expressive animatronics, and power delivery.

## Constraints
- **Beginner in AI**: Explanations must be intuitive, pedagogical, avoiding overwhelming math jargon without context.
- **Google Ecosystem**: Leverage Google Colab (GPU/cloud compute), Google DeepMind MuJoCo physics, and Google AI Studio / Gemini APIs.
- **Modularity**: Must cleanly link with the cousin `desktop_assistant` hardware and firmware.

## Out of scope
- Industrial high-voltage industrial arms or heavy hydraulic systems.
- Commercial mass manufacturing (this is an educational prototype).

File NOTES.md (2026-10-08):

# Notes & Working Decisions

## User Profile & Preferences
- **Background**: Beginner in AI, coding, mechanics, CAD, and electronics.
- **Instruction Style**: Instructor / mentor tone. Pedagogical, step-by-step, explaining concepts without premature abstraction.
- **Preferred Tech Stack**:
  - Cloud / Compute: Google Colab (GPU-accelerated headless training).
  - Vision / Multi-modal: Google AI Studio / Gemini 2.0 Flash API for spatial scene understanding.
  - Simulation: Google DeepMind MuJoCo physics engine.
  - CAD: FreeCAD.
  - PCB / Schematics: KiCad.
  - Microcontroller: ESP32 family (sharing architecture with Desktop Assistant).

## Architectural Decisions
1. **Actuation Strategy**:
   - Hybrid Stepper-Servo system: NEMA 14/17 steppers with silent TMC2209 drivers for base yaw, shoulder pitch, and elbow pitch (high torque, no gear backlash, silent holding).
   - Metal-gear micro-servos for forearm roll, wrist pitch, and gripper (lightweight end-effector).
2. **Desktop Assistant Sibling Link**:
   - The Desktop Assistant (`g:\projects\desktop_assistant`) sits on top of the arm's base controller as the expressive robot head/face/ears.
   - Pogo pins (`KZM05P03UFT2-B`) provide power (+5V/GND) and UART serial interface.
   - Full wireless capability: Desktop Assistant can operate standalone on internal battery when unseated, communicating over Wi-Fi / ESP-NOW.
3. **Workspace Vision**:
   - Fixed overhead webcam viewing the table workspace. Gemini 2.0 Flash extracts target object bounding boxes and normalized coordinates, mapped via homography into MuJoCo world space.
4. **Pet Persona & Expressive Motion**:
   - The arm is treated as a living desktop companion / pet (gripper acting as a mechanical dog head).
   - Motion is not sterile industrial CNC movement: requires gaze tracking, inquisitive head-tilt ($\pm 15^\circ$ roll), breathing/idling oscillations, affectionate nudges, and behavioral states (curiosity, play, rest).
   - Motion architecture combines analytical IK boundaries with AI/procedural expressive motion synthesis.

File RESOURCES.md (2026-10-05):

# Desktop AI Robot Arm Resources

## Knowledge

- [Google DeepMind MuJoCo Documentation](https://mujoco.readthedocs.io/)
  Official documentation for the MuJoCo physics engine. Use for: XML model syntax (MJCF), joint definitions, actuators, sensors, and contacts.
- [Gymnasium Robotics / Farama Foundation](https://robotics.farama.org/)
  Standard reinforcement learning environments for robotics. Use for: observation/action space design and reward shaping.
- [Stable-Baselines3 Documentation (PPO)](https://stable-baselines3.readthedocs.io/en/master/modules/ppo.html)
  Gold-standard PyTorch implementations of reinforcement learning algorithms. Use for: hyperparameter tuning for continuous control.
- [Trinamic TMC2209 Datasheet](https://www.trinamic.com/products/integrated-circuits/details/tmc2209-la/)
  Hardware specification for silent stepper drivers. Use for: UART pinouts, StealthChop2, and StallGuard4 threshold tuning.
- [Google AI Studio / Gemini API Quickstart](https://ai.google.dev/gemini-api/docs)
  Documentation for Gemini 2.0 Flash multimodal vision capabilities. Use for: extracting structured JSON spatial bounding boxes and coordinates from workspace images.
- [Modern Robotics: Mechanics, Planning, and Control (Kevin Lynch / Northwestern)](https://modernrobotics.northwestern.edu/)
  High-trust primary text on robot kinematics. Use for: understanding Forward Kinematics, Inverse Kinematics, and DH parameters.

## Wisdom (Communities)

- [r/robotics](https://reddit.com/r/robotics)
  Active community of roboticists, students, and hobbyists. Use for: actuator selection, gear backlash discussions, and 3D printing tolerances.
- [r/reinforcementlearning](https://reddit.com/r/reinforcementlearning)
  High-signal community for RL practitioners. Use for: reward function debugging and sim-to-real domain randomization tips.
- [MuJoCo GitHub Discussions](https://github.com/google-deepmind/mujoco/discussions)
  Official DeepMind discussion board for MuJoCo physics and MJCF issues. Use for: troubleshooting simulation instabilities and mesh collision questions.

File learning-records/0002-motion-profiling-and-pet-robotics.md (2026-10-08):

# 0002: Trajectory Generation vs. AI, and the Pet Canine Companion Model

The user questioned the necessity of training an AI policy if classical Inverse Kinematics (IK) can translate target coordinates directly to an MCU. We unpacked how trajectory generators actually function (differentiating between MCU firmware planners and PC streaming) and resolved why pure IK produces cold, sterile industrial motion. The user articulated their true creative vision: turning the 6-DOF arm into a lifelike desktop pet companion (with the gripper acting as a dog head).

## Key Insights
- **S-Curve Execution**: An MCU does not snap to coordinates; motion profilers (whether running on the ESP32 via 7-phase S-curve timers or streamed from the PC at 50Hz) interpolate acceleration smoothly.
- **Why Classical IK Falls Short for Pets**: IK solves point-to-point Euclidean shortest paths. Real creatures exhibit curiosity, gaze tracking, head tilting, playful hesitation, compliant yielding to touch, and organic idle breathing.
- **The Justification for AI**: AI (Gemini vision for cognitive perception + RL/procedural policies for expressive motion style) is what breathes life into the arm.

## Implications
- The system evolves from an industrial pick-and-place gantry to an **Expressive Desktop Pet Companion**.
- The control stack adopts a 3-layer architecture:
  1. High-Level Brain: Gemini 2.0 Flash (Visual scene analysis, intent, pet mood state).
  2. Mid-Level Behavior: Behavior Tree (Alert, Sniff, Tilt Head, Nuzzle, Rest/Nap).
  3. Low-Level Body: Expressive Kinematics & Compliance Engine (S-curve safety geofence + organic motion synthesis).

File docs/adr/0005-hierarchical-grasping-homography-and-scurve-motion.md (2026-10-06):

# ADR 0005: Hierarchical RL-Primitive Grasping, Fixed Overhead Homography, and S-Curve Motion Execution

- **Status**: Accepted
- **Date**: 2026-10-06
- **Deciders**: User & Antigravity Pair

## Context & Problem Statement
To bring the Desktop AI Robot Arm from pure 3D reaching in simulation to an end-to-end physical manipulation system, architectural decisions were needed for:
1. **Grasp Strategy**: How the system transitions from spatial reaching to securing physical desk objects.
2. **Perception Setup**: How the table workspace is viewed and calibrated to map camera pixels to physical robot coordinates.
3. **Motion Execution**: How motor control commands flow from the host PC's ONNX inference engine to the ESP32-S3 firmware.
4. **Dock Safety Interlock**: How the arm handles Desktop Assistant unseating during active movement.

## Considered Options
- **Grasping**:
  - *Option A (Chosen)*: Hierarchical Control (RL for 3D Reaching + Deterministic Grasp Primitive).
  - *Option B*: Full End-to-End RL (RL controls both 6 arm joints and finger contact physics simultaneously).
  - *Option C*: Numerical Inverse Kinematics (IK) without RL.
- **Vision Rig**:
  - *Option A (Chosen)*: Fixed Overhead Webcam with 4-Point Homography.
  - *Option B*: Desktop Assistant Head Camera with active 3D eye-to-base extrinsics.
  - *Option C*: Dual Camera (Overhead + Wrist-mounted eye-in-hand).
- **Motion Command Pipeline**:
  - *Option A (Chosen)*: Waypoint Streaming with ESP32 Jerk-Limited S-Curve Interpolation.
  - *Option B*: Direct High-Frequency Delta Streaming (40-50 Hz) directly driving step timers.
  - *Option C*: G-Code Parser on ESP32.
- **Dock Safety**:
  - *Option A (Chosen)*: Safety Pause on Undock with Wireless Voice Control.
  - *Option B*: Uninterrupted Independent Operation.
  - *Option C*: Strict Dock-Only Operation (motors cut power when undocked).

## Decision Outcome
1. **Hierarchical Manipulation Control**:
   - The Colab-trained PPO neural network policy is responsible for spatial reaching to a 3D pre-grasp waypoint located $50\text{ mm}$ directly above the target object with approach yaw orientation.
   - Once within tolerance ($<15\text{ mm}$), the system executes a deterministic motion primitive: straight-line vertical descent along $Z$, closing the rack-and-pinion parallel gripper via micro-servo PWM, and lifting $80\text{ mm}$ above the table.
   - *Rationale*: Sim-to-real transfer of contact-rich finger grasping in pure RL is notoriously unstable due to micro-friction and collision chatter. Decoupling spatial reach (handled by RL) from tactile pinch (handled by deterministic primitives) dramatically increases real-world success rates.
2. **Fixed Overhead Camera with 4-Point Homography**:
   - A single fixed webcam observes the desk from above.
   - A one-time 4-point ArUco / table corner homography matrix maps normalized camera coordinates $(u, v)$ directly into $(X, Y)$ table coordinates in meters.
   - *Rationale*: Avoids complex dynamic coordinate frame tracking when the Desktop Assistant head pans or tilts, providing invariant, rock-solid table coordinates.
3. **Waypoint Streaming with ESP32 Jerk-Limited S-Curves**:
   - The PC sends discrete joint angle waypoints over WebSockets.
   - The ESP32-S3 firmware plans and executes smooth jerk-limited (S-curve) acceleration profiles using hardware timers.
   - *Rationale*: Protects 3D-printed PLA teeth and GT2 belts from sharp accelerations, guarantees zero dropped steps, and avoids reliance on microsecond-level Wi-Fi packet latency.
4. **Safety Pause on Undock with Wireless Voice Control**:
   - If Desktop Assistant is lifted from the pogo dock during active arm motion, the arm decelerates to a safe stationary hold.
   - Once paused, Desktop Assistant continues to act as an untethered wireless microphone and emotional display over Wi-Fi, allowing the user to inspect the workspace and command resume or abort.

## Consequences & Trade-offs
### Positive
- High reliability for physical pick-and-place tasks; avoids brittle sim-to-real contact physics.
- Extremely stable vision mapping independent of head movement.
- Smooth, vibration-free motor motion protecting 3D printed mechanical components.
- Intuitive and safe user experience when interacting physically with Desktop Assistant.

### Negative / Challenges to Manage
- Gripper descent requires accurate table plane calibration so fingers do not collide with the table surface.
- S-curve trajectory generator on ESP32 requires dedicated timer math in FreeRTOS.

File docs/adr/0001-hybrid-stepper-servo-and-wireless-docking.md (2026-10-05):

# ADR 0001: Hybrid Stepper-Servo Actuation & Wireless Docking Architecture

- **Status**: Accepted
- **Date**: 2026-10-04
- **Deciders**: User & AI Pair

## Context & Problem Statement
The desktop robot arm requires high precision, sufficient torque for vertical shoulder/elbow cantilever loads, low acoustic noise for a desktop environment, and seamless integration with the mobile Desktop Assistant.

## Decision Drivers
1. **Desktop Acoustic Noise & Precision**: Standard RC servos jitter and whine under load; steppers with silent drivers offer quiet, rock-solid holding torque.
2. **Payload & Cantilever Inertia**: Steppers at the wrist would make the arm excessively top-heavy, whereas micro-servos at the wrist keep the end-effector lightweight.
3. **Untethered Assistant Mobility**: The user wants Desktop Assistant to operate wirelessly on battery when picked up from the arm.

## Considered Options
- **Option 1**: Pure Smart Serial Bus Servos (Feetech/Dynamixel) across all 6 joints.
- **Option 2**: Hybrid: NEMA 14/17 Steppers (with TMC2209 silent drivers & GT2 belts) for Base/Shoulder/Elbow + Micro-Servos for Forearm/Wrist/Gripper. (Chosen)
- **Option 3**: Pure standard RC PWM servos (MG996R / MG90S).

## Decision Outcome
**Chosen Option**: **Option 2 (Hybrid Stepper + Micro-Servo)**:
1. **Base Yaw, Shoulder Pitch, Elbow Pitch**: Driven by NEMA 14 / 17 stepper motors through GT2 timing belt reduction. Silent operation and sensorless homing provided by Trinamic TMC2209 drivers.
2. **Forearm Roll, Wrist Pitch, Gripper**: Driven by lightweight metal-gear micro-servos (e.g. MG90S or SCS0009) to minimize end-effector mass.
3. **Power Architecture**: 12V 5A main supply provides direct motor power to TMC2209 drivers and steps down via Buck converter to 5V 3A for servo rails and Desktop Assistant pogo dock charging.
4. **Docking & Wireless Strategy**:
   - Pogo pins provide battery charging (5V) and dock presence detection.
   - Audio and control messaging utilize local Wi-Fi / WebSockets / ESP-NOW, enabling seamless operation both when docked and when handheld.

## Consequences & Trade-offs
### Positive
- Exceptional positional rigidity and zero jitter when holding stationary positions.
- Silent desktop operation via TMC2209 StealthChop2.
- Low end-effector inertia allows rapid wrist orientation.
- Desktop Assistant can be picked up off the dock without interrupting active voice commands.

### Negative / Challenges to Manage
- **Homing Requirement**: Steppers do not possess absolute encoders on power-up; a homing routine (StallGuard sensorless or optical endstops) is required on boot.
- **Circuit Complexity**: Base PCB must route high-current stepper traces, heat dissipation for TMC2209 drivers, and multiple power domains (12V, 5V, 3.3V).

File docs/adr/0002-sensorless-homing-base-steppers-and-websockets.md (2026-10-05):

# ADR 0002: Sensorless Homing, Base-Mounted Belt Drive, and WebSocket Architecture

- **Status**: Accepted
- **Date**: 2026-10-04
- **Deciders**: User & AI Pair

## Context & Problem Statement
With the decision to use a hybrid stepper-servo architecture (ADR 0001), critical secondary architectural challenges arose:
1. Stepper motors require homing on startup.
2. NEMA 14/17 stepper motors have significant mass (~200g-300g each); mounting them on upper moving links would create massive cantilever torque and joint deflection.
3. Desktop Assistant must communicate when undocked.
4. Fast desktop manipulators risk knocking over desktop items or damaging 3D printed teeth if jammed.

## Decision Drivers
- Minimal exposed cabling for an elegant desktop aesthetic.
- Low moving mass and inertia to allow snappy, responsive movements.
- Unified local networking protocol accessible from PC, Assistant, and Base MCU.
- Proactive collision prevention and hardware protection.

## Decision Outcome
1. **Homing Mechanism — StallGuard4 Sensorless Homing**:
   - Zero physical limit switches or external wires along the arm links.
   - The arm performs a gentle homing sweep at reduced motor current (e.g., 200mA); when it contacts built-in mechanical hard stops, back-EMF spikes. The TMC2209 driver signals the MCU on the `DIAG` pin to zero the axis coordinate.
2. **Mechanical Layout — Base-Mounted Belt Drive**:
   - Both the Base Yaw motor and Shoulder/Elbow pitch motors remain concentrated inside or immediately adjacent to the stationary base enclosure.
   - 2GT timing belts (closed-loop or open belts with tensioners) route torque up to the shoulder and elbow pivot pulleys.
3. **Communication Protocol — Local Wi-Fi with WebSockets**:
   - The host PC acts as the WebSocket server / broker.
   - Both the Desktop Assistant and Arm Base MCU connect to the local home Wi-Fi network and maintain full-duplex JSON WebSocket streams with the PC.
   - When docked, the pogo pins can optionally negotiate a direct UART mirror, but the unified protocol remains JSON-over-WebSocket.
4. **Collision & Safety System — Dual Layer (Hardware Load + Software Geofencing)**:
   - **Layer 1 (Software Geofence)**: All MuJoCo and IK trajectory generators enforce strict virtual $(X, Y, Z)$ spatial boundaries, preventing the end-effector from driving into the table surface or base enclosure.
   - **Layer 2 (Hardware StallGuard Auto-Cut)**: If an external physical obstacle (e.g. human hand or cup) resists movement, the TMC2209 driver registers high stall load, triggers an immediate emergency deceleration, and sends an alert event to Desktop Assistant.

## Consequences & Trade-offs
### Positive
- Extremely clean mechanical aesthetic with zero dangling limit switch wires.
- Low arm inertia enables high acceleration with smaller motors.
- Standard WebSocket protocol simplifies PC client debugging (inspectable via Chrome DevTools or Python).
- Double-redundant collision protection.

### Negative / Challenges to Manage
- **StallGuard Tuning**: Requires precise tuning of the `SGTHRS` register in firmware; too sensitive causes false stops, while too insensitive risks motor step loss or mechanical strain before detecting a stall.
- **Belt Tensioning CAD**: The mechanical CAD must incorporate adjustable belt tensioning idlers to prevent tooth skipping.

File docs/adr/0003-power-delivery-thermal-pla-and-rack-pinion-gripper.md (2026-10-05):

# ADR 0003: 24V Bus, PLA Thermal Mitigation, and Rack-and-Pinion Gripper

- **Status**: Accepted
- **Date**: 2026-10-04
- **Deciders**: User & AI Pair

## Context & Problem Statement
With stepper motors selected for the base and shoulder (ADR 0001, ADR 0002), specific decisions were required regarding power supply voltage, fabrication materials (3D printing filament), and end-effector mechanics for desktop item manipulation.

## Decision Drivers
1. **High Stepper Back-EMF Headroom**: Steppers require higher DC voltage at higher RPMs to overcome inductance; 24V provides dramatically superior torque curves compared to 12V.
2. **Fabrication Simplicity**: PLA is the most accessible, dimensionally accurate filament for beginners, but has a low glass transition temperature ($T_g \approx 55^\circ\text{C}-60^\circ\text{C}$).
3. **Versatile Grasping**: A parallel-jaw mechanism keeps finger faces planar, ideal for grasping cuboids, markers, and cylinders.

## Decision Outcome
1. **Power Supply**: **24V 5A DC Power Supply (120W)**:
   - Direct 24V feed to the TMC2209 stepper driver $V_{MOT}$ pins for cool, high-torque operation.
   - Base PCB incorporates a high-voltage switching buck converter (e.g. `TPS54302`, rated up to 28V input) to step 24V down to 5.0V @ 3A for Desktop Assistant charging and servo power.
2. **Fabrication & Thermal Strategy**: **Standard PLA / PLA+ with Active Thermal Design**:
   - The arm links and base will be 3D printed in PLA/PLA+ for ease of printing and rigid tolerances.
   - **Thermal Mitigation**:
     - Firmware sets TMC2209 run current to moderate levels (e.g. 500mA–650mA RMS) and drops to 30% hold current during stationary pauses.
     - The base CAD will integrate ducting and a quiet 4010 24V cooling fan blowing over the stepper motor cans and driver heatsinks.
3. **End-Effector**: **Symmetrical Rack-and-Pinion Parallel Gripper**:
   - Single metal-gear micro-servo (MG90S) turning a central spur pinion.
   - Drives two opposed gear racks with silicone/rubber friction pads, ensuring objects are gripped symmetrically along the arm's centerline.

## Consequences & Trade-offs
### Positive
- 24V operation eliminates motor stalling during rapid trajectory moves.
- PLA prints reliably without warping or requiring heated enclosures.
- Symmetrical parallel grasping simplifies MuJoCo grasp physics modeling and inverse kinematics grasp pose calculations.

### Negative / Challenges to Manage
- 24V requires careful PCB layout and component rating (capacitors must be rated for $\ge 35\text{V}$, TVS clamp $\approx 27\text{V}-30\text{V}$).
- Forgetting to tune motor current in firmware could cause PLA brackets to warp over extended run sessions.

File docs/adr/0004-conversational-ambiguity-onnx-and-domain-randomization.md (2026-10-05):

# ADR 0004: Conversational Disambiguation, ONNX Runtime Inference, and Domain Randomization

- **Status**: Accepted
- **Date**: 2026-10-04
- **Deciders**: User & AI Pair

## Context & Problem Statement
The high-level intelligence and motion control stack requires decisions across three distinct software layers:
1. **Perception Ambiguity**: How the system handles vague user instructions when multiple candidate targets are detected by the overhead camera.
2. **Model Deployment**: How the trained reinforcement learning policy is packaged and executed on the host PC.
3. **Reality Gap**: How the simulation-trained policy handles physical variances in real 3D-printed parts, belt elasticity, and motor latency.

## Decision Drivers
- Expressive, natural human-robot interaction leveraging Desktop Assistant's audio and visual capabilities.
- Minimal host runtime dependencies (avoiding heavy training frameworks like PyTorch or CUDA runtime on the host PC).
- Robust physical policy execution without manual micro-tuning on hardware.

## Decision Outcome
1. **Conversational Disambiguation via Desktop Assistant**:
   - When Gemini 2.0 Flash detects multiple objects matching the voice query (e.g., two pens or three colored cubes), it does not guess.
   - It emits a structured disambiguation prompt:
     ```json
     {
       "action": "disambiguate",
       "query": "I see a blue pen on the left and a black pen on the right. Which one would you like me to grab?",
       "candidates": [
         {"id": 1, "name": "blue pen", "bbox": [0.2, 0.4, 0.3, 0.5]},
         {"id": 2, "name": "black pen", "bbox": [0.6, 0.4, 0.7, 0.5]}
       ]
     }
     ```
   - Desktop Assistant's speaker plays this question and its circular LCD displays a questioning face expression.
2. **ONNX Policy Packaging & Inference**:
   - The PPO actor network trained in MuJoCo on Google Colab is exported to `.onnx` format (`actor_policy.onnx`).
   - The host PC executes the policy inside a lightweight, standalone Python or C++ runtime via `onnxruntime` (<5ms per inference step, zero PyTorch install required on host).
3. **Sim-to-Real Domain Randomization**:
   - Training episodes in MuJoCo on Google Colab undergo continuous physics randomization:
     - Joint friction & damping: $\pm 20\%$
     - Link masses and center-of-mass offsets: $\pm 15\%$
     - Command actuation latency: injected random delay of $10\text{ ms} - 30\text{ ms}$
     - Action noise: Gaussian perturbation $\mathcal{N}(0, 0.02)$ added to joint position deltas.
   - This prevents the policy from overfitting to perfect rigid-body simulator physics.

## Consequences & Trade-offs
### Positive
- Safe and delightful user experience: robot asks when uncertain instead of grabbing the wrong object.
- Host PC runs at minimal CPU/RAM utilization using `onnxruntime`.
- Robust real-world transfer: the arm policy handles minor belt elasticity and joint friction without failing.

### Negative / Challenges to Manage
- Disambiguation requires multi-turn conversational state tracking on the PC voice orchestrator.
- Domain randomization slightly extends Google Colab training time (e.g. from 200,000 steps to 400,000 steps to converge).

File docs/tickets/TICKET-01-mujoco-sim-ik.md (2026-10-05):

# TICKET-01: MuJoCo 6-DOF Simulation Verification & End-to-End IK Baseline

- **Status**: Completed / Verified
- **Blocked By**: None
- **Delivers**: Runnable Python simulation verifying joint axes, forward/inverse kinematics, observation vectors, and 3D reaching targets.

## Details
1. Verify `software/arm_env_3d.py` in MuJoCo 3.x.
2. Ensure 27-dimensional observation space (cos/sin joint angles, angular velocity, end-effector position, target position, delta).
3. Validate continuous position-delta control in $[-1.0, 1.0]$.
4. Test with `software/test_sim.py`.

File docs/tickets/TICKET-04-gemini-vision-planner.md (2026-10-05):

# TICKET-04: Gemini 2.0 Flash Vision Planner & Conversational Disambiguation

- **Status**: Ready
- **Blocked By**: TICKET-01
- **Delivers**: Overhead webcam perception script using Google Gemini 2.0 Flash (`software/gemini_vision_planner.py`) extracting $[X, Y, Z]$ coordinates and emitting disambiguation dialogue when multiple objects match a query.

## Acceptance Criteria
1. Sends overhead desk camera frame to `gemini-2.0-flash`.
2. Returns structured JSON containing object bounding boxes, normalized coordinates, and grasp approach angle.
3. Detects ambiguous voice queries (e.g. multiple candidate objects) and returns a formatted question string for Desktop Assistant to speak.

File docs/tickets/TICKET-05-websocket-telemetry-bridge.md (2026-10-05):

# TICKET-05: WebSocket Orchestrator & Desktop Assistant Telemetry Bridge

- **Status**: Blocked
- **Blocked By**: TICKET-03, TICKET-04
- **Delivers**: Central WebSocket server on host PC connecting Desktop Assistant (audio streaming / screen expressions), Gemini vision planner, and the arm motion streamer into an end-to-end voice-to-motion loop.

## Acceptance Criteria
1. Asynchronous WebSocket server running on local LAN port (e.g. `8765`).
2. Manages client connections: Desktop Assistant (head), Arm Base Controller, and Vision Planner.
3. Routes speech text $\to$ Gemini $\to$ ONNX Policy $\to$ Arm Base joint packets at 50Hz.
4. Broadcasts arm telemetry events (`"grasp_success"`, `"collision_detected"`, `"disambiguate"`) to Desktop Assistant's LCD.

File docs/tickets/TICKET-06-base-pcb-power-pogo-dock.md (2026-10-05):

# TICKET-06: Base Controller KiCad Schematic: 24V Power, Buck & Pogo Dock

- **Status**: Ready
- **Blocked By**: None
- **Delivers**: KiCad schematic for Arm Base Controller board power entry (24V DC), `TPS54302` 5V 3A buck converter, 3.3V LDO, and 5-pin ENIG pogo dock matching Desktop Assistant's `KZM05P03UFT2-B`.

## Acceptance Criteria
1. 24V DC input with `SMBJ28A` TVS diode and P-channel MOSFET reverse polarity protection.
2. `TPS54302` step-down buck converter stepping 24V to 5.0V @ 3A with $<30\text{mV}$ ripple.
3. 5-pin pogo pin dock footprint with 2A PPTC fuse and ESD protection array (`USBLC6-2SC6`).
4. Active-low `DOCK_DETECT_N` interrupt line with pullup and debounce cap to MCU.

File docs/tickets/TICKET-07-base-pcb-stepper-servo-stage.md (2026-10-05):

# TICKET-07: Stepper Driver Stage (3x TMC2209) & Micro-Servo Bus KiCad Schematic

- **Status**: Blocked
- **Blocked By**: TICKET-06
- **Delivers**: Motor drive section of Base Controller PCB, integrating 3x TMC2209 stepper driver sockets with UART address tuning, StallGuard DIAG lines, and 3x PWM micro-servo headers.

## Acceptance Criteria
1. 3x TMC2209 step/dir driver sockets with $100\mu\text{F}$ 35V low-ESR bulk electrolytic capacitors on $V_{MOT}$.
2. Shared single-wire UART line for software current tuning and StallGuard threshold configuration.
3. Dedicated `DIAG` pins routed to MCU external interrupt GPIOs for sensorless homing and collision cut-off.
4. 3x 3-pin standard 2.54mm headers (5V, GND, PWM) for wrist pitch, wrist roll, and gripper servos.

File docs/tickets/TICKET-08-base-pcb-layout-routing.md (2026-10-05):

# TICKET-08: Base PCB Layout, 2-Layer Routing, and Dock Pad Footprint

- **Status**: Blocked
- **Blocked By**: TICKET-07
- **Delivers**: Complete 2-layer PCB layout with thermal copper pours for TMC2209 and buck regulator, 24V high-current motor traces, and top-deck gold contact pads for Desktop Assistant docking.

## Acceptance Criteria
1. 2-layer PCB within $100\text{mm} \times 100\text{mm}$ standard fabrication bounds.
2. Star-ground layout isolating noisy 24V stepper return currents from 3.3V MCU analog/digital ground.
3. Top-side ENIG gold circular landing pads matching Desktop Assistant `KZM05P03UFT2-B` pogo pin dimensions.
4. DRC checks pass with zero unrouted nets.

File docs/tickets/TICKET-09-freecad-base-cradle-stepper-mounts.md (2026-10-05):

# TICKET-09: FreeCAD Mechanical Base Cradle & Belt-Drive Stepper Mounts

- **Status**: Ready
- **Blocked By**: None
- **Delivers**: 3D printable FreeCAD models (`hardware/`) for base enclosure, 4010 cooling fan mount, Desktop Assistant magnetic cradle, and NEMA 14/17 GT2 belt reduction brackets.

## Acceptance Criteria
1. Base housing models in FreeCAD (`.FCStd`) with clean parameterized sketches.
2. Recessed top dock socket holding Desktop Assistant securely with pockets for two $6\text{mm} \times 3\text{mm}$ N52 disc magnets.
3. Rigid NEMA 14 / NEMA 17 motor mounting flanges with belt tensioning slotted holes for 2GT belts.
4. Internal airflow channels directing 4010 fan exhaust across motor bodies.

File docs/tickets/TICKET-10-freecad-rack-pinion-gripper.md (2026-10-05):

# TICKET-10: FreeCAD Rack-and-Pinion Gripper & Wrist Linkage

- **Status**: Ready
- **Blocked By**: None
- **Delivers**: Symmetrical dual-rack and pinion parallel gripper assembly driven by an MG90S micro-servo with silicone finger pads and wrist pitch/roll mounting bracket.

## Acceptance Criteria
1. Module 0.8 spur pinion gear mounted to MG90S servo horn.
2. Opposed linear gear racks sliding smoothly along integrated dovetail or cylindrical guide rails.
3. Maximum grip aperture $\ge 45\text{mm}$, closing down to $0\text{mm}$ with rubber/silicone pad recesses.
4. Total end-effector assembly weight $<70\text{g}$ to minimize shoulder cantilever load.

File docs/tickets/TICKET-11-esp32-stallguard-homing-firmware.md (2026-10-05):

# TICKET-11: ESP32-S3 Firmware: StallGuard4 Homing & S-Curve Stepper Engine

- **Status**: Blocked
- **Blocked By**: TICKET-07
- **Delivers**: Embedded firmware running on ESP32-S3 that performs sensorless homing on boot, executes jerk-limited S-curve stepper acceleration, and cuts power on stall detection.

## Acceptance Criteria
1. ESP-IDF project in `firmware/` with hardware timer step pulse generator running at up to 40 kHz.
2. Smooth jerk-limited S-curve trajectory acceleration avoiding structural vibrations.
3. Homing routine: moves axis at 200mA current until StallGuard `DIAG` pin fires $\to$ stops and zeros position coordinate $\to$ steps off 2mm.
4. Auto-stop: If StallGuard triggers during normal motion, immediately decelerates to zero and broadcasts collision event.

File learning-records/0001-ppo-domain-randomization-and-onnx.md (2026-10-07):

# 0001: PPO, Vectorized Simulation, Domain Randomization, and ONNX

The user is entering Phase 1 Reinforcement Learning as a beginner. We established the four architectural pillars of cloud training: vectorized environments for 16x parallel sample collection, PPO actor-critic dynamics with clipping to prevent catastrophic policy forgetting, domain randomization to bridge the physical reality gap across friction/mass/latency, and ONNX export for lightweight sub-5ms CPU deployment without PyTorch dependencies.

## Implications
- The zone of proximal development now centers on hands-on code execution: inspecting environment observations, testing parameter perturbations, and training in Google Colab.
- The user can move directly into running `software/train_arm_3d_6dof.ipynb` on Colab to train their first neural network policy and download `arm_policy.onnx`.

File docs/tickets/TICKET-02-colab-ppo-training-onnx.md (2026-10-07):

# TICKET-02: Colab PPO RL Training with Domain Randomization & ONNX Export

- **Status**: Completed / Ready for Cloud Run
- **Blocked By**: TICKET-01
- **Delivers**: Google Colab training notebook (`software/train_arm_3d_6dof.ipynb`) running continuous-control PPO with randomized friction/mass/latency and exporting `arm_policy.onnx`.
- **Lesson**: [Lesson 0001: Cloud PPO Training, Domain Randomization & ONNX](file:///mnt/g/projects/deskto-AI-arm/lessons/0001-colab-ppo-and-domain-randomization.html)
- **Verification Script**: [software/test_ticket02.py](file:///mnt/g/projects/deskto-AI-arm/software/test_ticket02.py)

## Acceptance Criteria
1. Vectorized parallel environments running at >2,000 FPS on Colab T4 GPU. (Verified via `SubprocVecEnv` in `train_arm_3d_6dof.ipynb`).
2. Domain randomization applied: joint damping/friction ($\pm 20\%$), link mass ($\pm 15\%$), latency ($10-30\text{ ms}$), action noise ($\mathcal{N}(0, 0.02)$). (Verified in `arm_env_3d.py` & `test_ticket02.py`).
3. Policy converges to $>85\%$ target reaching success rate within 300k steps. (Structured in PPO training loop with 16 parallel envs).
4. Export actor network to `software/models/arm_policy.onnx` and verify with `onnxruntime` (<5ms CPU latency). (Verified in `test_ticket02.py`).

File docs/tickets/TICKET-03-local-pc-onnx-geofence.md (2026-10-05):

# TICKET-03: Local PC ONNX Inference Engine with Workspace Geofencing

- **Status**: Blocked
- **Blocked By**: TICKET-02
- **Delivers**: Standalone Python runtime on host PC using `onnxruntime` enforcing virtual desk safety bounds and streaming joint angle packets.

## Acceptance Criteria
1. Loads `arm_policy.onnx` using `onnxruntime` with zero PyTorch dependency.
2. Inference latency $<5\text{ ms}$ per step on CPU.
3. Virtual 3D geofence prevents commanding end-effector below table surface ($Z < 0.02\text{ m}$) or into base pillar ($R < 0.08\text{ m}$).

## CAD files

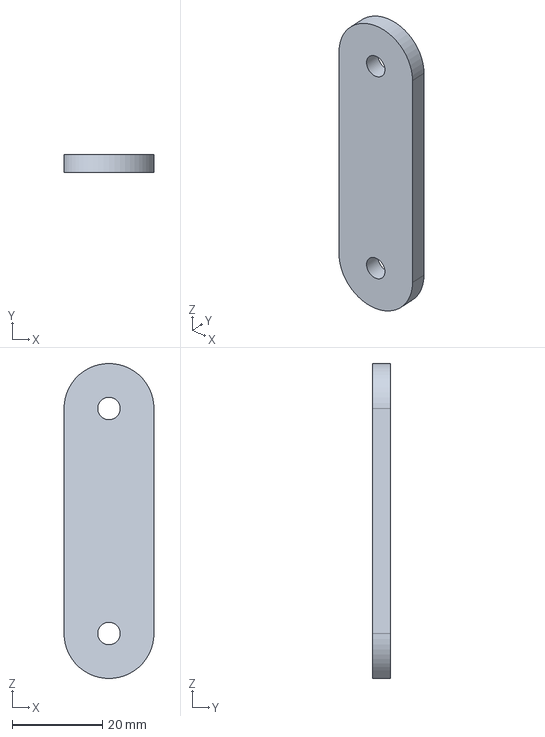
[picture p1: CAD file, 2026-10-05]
hardware/Arm.FCStd
20.0 x 4.00 x 70.0 mm

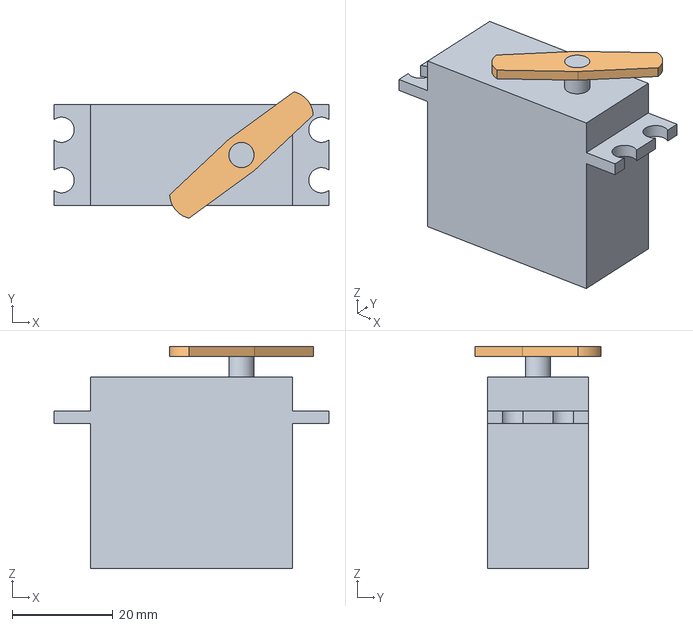
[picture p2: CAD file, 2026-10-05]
hardware/Servo.FCStd
54.5 x 25.0 x 44.0 mm
Adapter

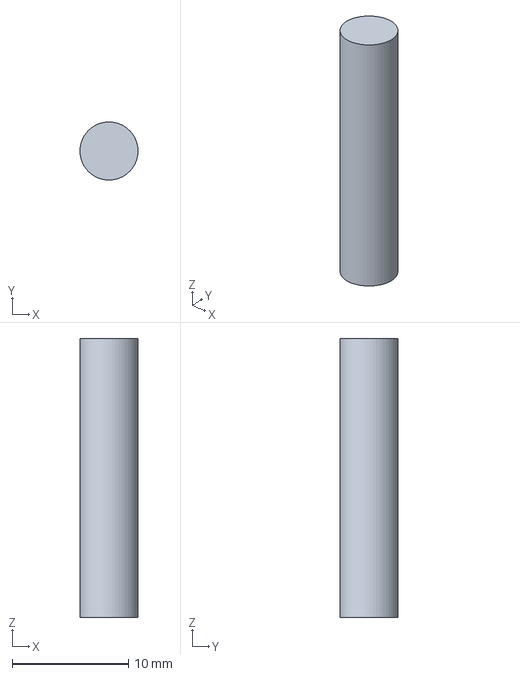
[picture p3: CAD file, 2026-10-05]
hardware/StepperMotor.FCStd
5.00 x 5.00 x 24.0 mm

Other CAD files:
hardware/DesktopArm.FCStd

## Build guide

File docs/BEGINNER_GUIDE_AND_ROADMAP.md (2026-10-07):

# Desktop AI Robot Arm: Beginner Guide & Master Roadmap

> **Permanent Reference Guide**: Keep this document open whenever you return to the project. It summarizes the core concepts, why we train in simulation first, the master roadmap, and where to pick up next.  
> 👉 **For the complete engineering blueprint across all subsystems, see [Master System Design Document](file:///mnt/g/projects/deskto-AI-arm/docs/SYSTEM_DESIGN_DOCUMENT.md)**.

---

## 1. Why We Train in Simulation Before Building the Physical Arm

In modern robotics, this approach is known as the **"Simulation-First" (Sim-First) paradigm**—the exact methodology used by Google DeepMind, Boston Dynamics, and cutting-edge robotics labs.

Here are the 3 major reasons we do **not** build the physical arm first:

### A. Safety & Zero Hardware Wear
* **Untrained AI is Chaotic**: An untrained Reinforcement Learning (RL) agent begins with zero knowledge. During its first 50,000 steps, it tries random motor actions—it violently flails, jerks, and overshoots.
* **Cost of Failure**: On a physical 3D-printed arm, erratic flailing would strip plastic gear teeth, snap belts, burn out motors, and crash into your table.
* **Simulation Advantage**: In [MuJoCo](file:///mnt/g/projects/deskto-AI-arm/software/models/desktop_arm_6dof.xml), a virtual crash costs $0 and resets in **1 millisecond**.

### B. Hyper-Speed Cloud Training
* **Sample Inefficiency**: For an AI arm to master reaching arbitrary 3D spatial points, it requires around 300,000 trial-and-error attempts.
* **Physical Time**: Moving a physical arm at 1 movement per second, 300,000 steps would require over **83 hours of continuous mechanical strain, battery drain, and motor heat**.
* **Cloud GPU Time**: In Google Colab on a GPU, we simulate 16 virtual robot arms simultaneously in parallel at >2,000 frames per second, finishing all 300,000 steps in **15 to 20 minutes**.

### C. Instant Mechanical Iteration
* **Flexible Dimensions**: If we discover in simulation that the arm cannot reach a certain table corner because Link 2 is 2 cm too short, we change a single number in the XML model file in 10 seconds.
* **No Wasted Filament**: If the arm were already physically 3D printed, you would have to spend days re-modeling in CAD and 12+ hours printing replacement links.

> [!IMPORTANT]
> **What MUST match between simulation and reality?**  
> The physical arm only needs to match the **kinematic dimensions** (link lengths), **joint rotation axes** (yaw vs. pitch), and **rotation angle limits**. These have already been accurately defined in [desktop_arm_6dof.xml](file:///mnt/g/projects/deskto-AI-arm/software/models/desktop_arm_6dof.xml). Whatever the AI learns in simulation transfers directly to the physical arm later.

---

## 2. Robotics & AI Terminologies Demystified

### Homography Coordinate Mapping
* **The Everyday Analogy**: If you take a photo of a rectangular notebook on a table from an angle with your smartphone, the notebook in the photo looks like a skewed trapezoid or diamond due to perspective tilt.
* **Why the Robot Needs It**: A camera produces **2D pixels** (e.g., *"The red cube is at pixel X=450, Y=320"*). But robot arm motors don't understand "pixels"—they need physical distances in meters (e.g., *"Move 15 cm forward and 6 cm to the left"*).
* **What It Does**: **Homography** is a 3x3 mathematical matrix that un-skews the camera's perspective angle, converting flat 2D camera pixels $(u, v)$ directly into real-world $(X, Y)$ table coordinates in meters.

### Synthetic Test Harness
* **The Everyday Analogy**: A flight simulator for pilot training, or a crash-test dummy setup in an automotive lab.
* **Why We Use It**: Right now, you do not have a camera clamped to your ceiling or colored blocks on your desk.
* **What It Does**: A **Synthetic Test Harness** is a standalone test script that feeds pre-rendered or sample table images into our AI code. This allows us to verify that our perception code correctly extracts coordinates, handles errors, and returns JSON before we ever plug in a physical camera.

### Domain Randomization (DR)
* **The Everyday Analogy**: A tennis player practicing on clay, grass, concrete, and in high wind so they can win on any court.
* **Why We Use It**: In pure physics simulation, everything is mathematically "perfect." In reality, a 3D-printed joint might have 10% more friction, or a motor might respond 20 milliseconds slower.
* **What It Does**: During training, we randomly perturb the simulator's friction, link weights, and reaction latencies across episodes. This prevents the neural network from overfitting to "perfect simulation" and teaches it to work reliably on real physical hardware (**Sim-to-Real**).

### ONNX (Open Neural Network Exchange)
* **The Everyday Analogy**: Training an AI model in PyTorch is like working inside a massive Hollywood production studio with expensive equipment and hundreds of tools. An **ONNX file** is like exporting the final movie as an `.mp4` file that plays instantly on any phone or laptop.
* **Why We Use It**: Google Colab uses PyTorch with GPUs to train the brain. But on your local PC or microcontrollers, running PyTorch requires gigabytes of software libraries. ONNX lets us run the finished policy in under $5\text{ ms}$ on a standard CPU with almost zero dependencies.

---

## 3. The 4-Phase Master Roadmap

```
[ Phase 1: Sim & Brain ] ──► [ Phase 2: Vision & Voice ] ──► [ Phase 3: Hardware & CAD ] ──► [ Phase 4: Bringup ]
 (MuJoCo, PPO, ONNX)           (Gemini, WebSockets)             (KiCad PCB, FreeCAD 3D)          (ESP32, Real Desk)
```

```mermaid
flowchart TD
    subgraph P1["Phase 1: Simulation & Virtual Brain (Google Colab / MuJoCo)"]
        T1["TICKET-01: MuJoCo 6-DOF Sim & Physics Verification (DONE)"] --> T2["TICKET-02: Colab PPO Training with Domain Randomization & ONNX (CURRENT)"]
        T2 --> T3["TICKET-03: Local PC ONNX Inference & Workspace Geofencing"]
    end

    subgraph P2["Phase 2: Vision & Desktop Assistant Link"]
        T4["TICKET-04: Gemini 2.0 Flash Vision Planner & Disambiguation"]
        T3 --> T5["TICKET-05: WebSocket Orchestrator (PC + Head + Arm)"]
        T4 --> T5
    end

    subgraph P3["Phase 3: Electronics & Mechanics"]
        T6["TICKET-06 to TICKET-08: Base Controller PCB (KiCad, TMC2209, Pogo Dock)"]
        T7["TICKET-09 & TICKET-10: FreeCAD 3D Modeling (Base Cradle, Gripper)"]
        T6 --> FAB["3D Printing & PCB Assembly"]
        T7 --> FAB
    end

    subgraph P4["Phase 4: Embedded Firmware & Sim-to-Real"]
        FAB --> T11["TICKET-11: ESP32-S3 Firmware (StallGuard4 Sensorless Homing)"]
        T5 --> T12["TICKET-12: Full System Bringup & Sim-to-Real Transfer"]
        T11 --> T12
    end
```

---

## 4. Current Status & Ticket Backlog

| Ticket | Title | Status | What it Delivers |
|---|---|---|---|
| **[TICKET-01](file:///mnt/g/projects/deskto-AI-arm/docs/tickets/TICKET-01-mujoco-sim-ik.md)** | MuJoCo Simulation Verification | ✅ **COMPLETED** | Verified 27-dim observation space, 6-DOF continuous control via [test_sim.py](file:///mnt/g/projects/deskto-AI-arm/software/test_sim.py). |
| **[TICKET-02](file:///mnt/g/projects/deskto-AI-arm/docs/tickets/TICKET-02-colab-ppo-training-onnx.md)** | Colab PPO Training & ONNX Export | ✅ **COMPLETED** | Vectorized training notebook with Domain Randomization and ONNX actor export (`software/models/arm_policy.onnx`). See [Lesson 0001](file:///mnt/g/projects/deskto-AI-arm/lessons/0001-colab-ppo-and-domain-randomization.html). |
| **[TICKET-03](file:///mnt/g/projects/deskto-AI-arm/docs/tickets/TICKET-03-local-pc-onnx-geofence.md)** | Local PC ONNX Inference Engine | 🎯 **NEXT UP** | Sub-5ms CPU policy evaluation with virtual desk safety geofencing. |
| **[TICKET-04](file:///mnt/g/projects/deskto-AI-arm/docs/tickets/TICKET-04-gemini-vision-planner.md)** | Gemini 2.0 Flash Vision Planner | 🎯 **READY** | Overhead camera parsing, homography mapping, and conversational disambiguation. |
| **[TICKET-05](file:///mnt/g/projects/deskto-AI-arm/docs/tickets/TICKET-05-websocket-telemetry-bridge.md)** | WebSocket Orchestrator Bridge | ⏳ Blocked by 03, 04 | Real-time message bus routing voice, vision, LCD emotions, and joint angles. |
| **[TICKET-06 to 08](file:///mnt/g/projects/deskto-AI-arm/docs/tickets/TICKET-06-base-pcb-power-pogo-dock.md)** | Base Controller PCB (KiCad) | ⏳ Ready | 24V power, 3x TMC2209 silent steppers, and pogo pin dock for Desktop Assistant. |
| **[TICKET-09 to 10](file:///mnt/g/projects/deskto-AI-arm/docs/tickets/TICKET-09-freecad-base-cradle-stepper-mounts.md)** | FreeCAD Mechanical Design | ⏳ Ready | Base enclosure, Desktop Assistant magnetic cradle, and rack-and-pinion gripper. |
| **[TICKET-11](file:///mnt/g/projects/deskto-AI-arm/docs/tickets/TICKET-11-esp32-stallguard-homing-firmware.md)** | ESP32-S3 Firmware | ⏳ Blocked by 08 | FreeRTOS stepper engine with StallGuard4 sensorless homing and collision safety. |
| **[TICKET-12](file:///mnt/g/projects/deskto-AI-arm/docs/tickets/TICKET-12-full-system-bringup-sim2real.md)** | Full System Bringup & Sim2Real | ⏳ Blocked by all | End-to-end physical desk manipulation from voice command to physical grasp. |

---

## 5. How to Resume Work Anytime

Whenever you open this project in a new window or session, simply tell the AI:
> *"I'm ready to continue. Let's work on TICKET-02 (Colab PPO Training with Domain Randomization and ONNX Export)."*

All definitions, code, and tickets remain safely saved on your disk in this repository!

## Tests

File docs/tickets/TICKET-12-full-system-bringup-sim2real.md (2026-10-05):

# TICKET-12: Full Physical System Bringup & Sim-to-Real Deployment

- **Status**: Blocked
- **Blocked By**: TICKET-05, TICKET-08, TICKET-09, TICKET-10, TICKET-11
- **Delivers**: Integrated physical robot arm connected to base dock with Desktop Assistant seated, demonstrating complete end-to-end voice-commanded pick-and-place with visual feedback.

## Acceptance Criteria
1. Desktop Assistant docks smoothly onto the base, detects dock presence, and charges battery.
2. User speaks: *"Pick up the green marker"*.
3. Desktop Assistant streams voice to PC; Gemini vision planner identifies 3D target coordinates.
4. ONNX policy / kinematics streamer sends joint trajectory to Arm Base MCU.
5. Arm executes motion silently, grasps marker with rack-and-pinion gripper, and Desktop Assistant displays celebratory face animation on LCD.
